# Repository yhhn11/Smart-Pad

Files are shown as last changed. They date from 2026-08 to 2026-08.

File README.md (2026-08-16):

# Smart-Pad

**Smart-Pad** is an open-source, 3D-printed, automated optical reader for colorimetric assays.

A stepper motor rotates a circular sample plate underneath an **AS7341 11-channel spectral
sensor**. For every position the plate stops, the sensor's white LED illuminates the sample and
the light returned by it is recorded in **8 wavelength bands (415, 445, 480, 515, 555, 590, 630
and 680 nm)**. The result of each sample is either the raw sensor counts or an absorbance value
calculated against a blank, and it is sent to your phone/computer over Wi-Fi.

Everything is controlled by an **ESP32**, and the whole build is designed to be reproducible by
someone with no electronics background: print the parts, make about a dozen soldered
connections, install two free programs and click one button to load the firmware.

> **No programming knowledge is required to build and use the device.** Section 5 explains how
> the code works only for those who want to modify or calibrate it.

---

## Table of contents

1. [Choosing a firmware version: MQTT or Web server](#1-choosing-a-firmware-version-mqtt-or-web-server)
2. [Bill of materials](#2-bill-of-materials)
3. [Step 1 — Print the parts](#3-step-1--print-the-parts)
4. [Step 2 — Wire the electronics](#4-step-2--wire-the-electronics)
5. [Step 3 — Flash the firmware onto the ESP32](#5-step-3--flash-the-firmware-onto-the-esp32)
6. [Step 4 — Run a measurement](#6-step-4--run-a-measurement)
7. [Step 5 — How the code works](#7-step-5--how-the-code-works)
8. [Troubleshooting](#8-troubleshooting)
9. [License](#9-license)

---

## 1. Choosing a firmware version: MQTT or Web server

This repository contains **two independent firmwares** for exactly the same hardware. You build
the device once, then choose which of the two programs to load onto the ESP32. You can switch
between them at any time by simply flashing the other one — nothing in the hardware changes.

**The measurement itself is identical in both.** Same pinout, same homing routine, same plate
map, same number of readings per sample, same filtering, same absorbance maths, same validation
limits. The only thing that differs is **how the device talks to you**:

| | **`WEBSERVER VERSION`** | **`MQTT VERSION`** |
|---|---|---|
| **How you talk to it** | The ESP32 **creates its own Wi-Fi network**. You connect your phone or laptop to it and open a web page hosted by the device. | The ESP32 **joins your existing Wi-Fi** and exchanges short text messages with an MQTT broker (a small message server). |
| **Infrastructure needed** | None. | A Wi-Fi network + an MQTT broker running somewhere (e.g. Mosquitto on a PC or Raspberry Pi). |
| **User interface** | A ready-made control page with sliders and a results panel (built into the firmware, no app to install). | None included — you use any MQTT client (MQTT Explorer, Node-RED, Home Assistant, a Python script…). |
| **Internet / lab network** | Works anywhere, even with no network at all (a field or a fume hood with no coverage). | Requires the device and your computer to be on the same network as the broker. |
| **Data logging** | Manual — you read the numbers off the web page, which shows one position at a time. | Automatic — every result is published as it is measured, so anything subscribed to the topic keeps the full run. |
| **Multiple devices** | One device = one Wi-Fi network to connect to; you must switch networks to change device. | Many devices can publish to the same broker at once and be monitored from one screen. |
| **Diagnostics** | Serial monitor over USB (115200 baud). | Published to the `Debug` and `Notifications` topics — readable over the air. |
| **Remote firmware update** | No. | Yes (ElegantOTA — update over Wi-Fi at `http://<device-ip>/update`). |
| **Difficulty** | ⭐ Easiest — start here | ⭐⭐ Requires setting up a broker |

**Which one should I use?**

- **You just want to measure samples** → use the **Web server version**. It is self-contained:
  turn the device on, connect your phone to it, press a button, read the numbers.
- **You want the data to be logged automatically**, to run several Smart-Pads in a lab, or to
  integrate the readings into an existing system → use the **MQTT version**.

Because the measurement code is shared, a plate calibration (§7.4) done on one version is valid
on the other, and readings taken with either firmware are directly comparable.

---

## 2. Bill of materials

### Electronics

| Qty | Component | Notes |
|:---:|---|---|
| 1 | **ESP32 DevKit V1** (30 or 38 pin) | The "brain". Any common ESP32 DevKit board works. |
| 1 | **AS7341** spectral sensor breakout | The detector. Must have the on-board white LED (Adafruit and most clones do). |
| 1 | **28BYJ-48 stepper motor (5 V)** + **ULN2003 driver board** | Usually sold together as a kit. Rotates the sample plate. |
| 1 | **KY-010 photo-interrupter module** | Optical endstop — tells the device where "position zero" is. |
| 1 | **PD/QC/AFC Fast-Charge Decoy Trigger module (Type-C)** | Turns any USB-C phone charger into a 5 V power supply for the device. |
| 1 | USB-C charger, **5 V, 2 A or more** | Powers the whole device through the decoy module. |
| 1 | USB **data** cable for the ESP32 (micro-USB or USB-C) | Needed only to load the firmware. Many cheap cables are charge-only and will *not* work. |
| — | Thin wires (AWG 24–26) and solder | About a dozen connections. Dupont jumper wires also work but are less reliable. |

### Printed parts

9 STL files, listed in [Step 1](#3-step-1--print-the-parts). One standard 1 kg spool of filament
is more than enough for the whole set.

### Tools

Soldering iron, side cutters, a small screwdriver, and a 3D printer (or a printing service).

---

## 3. Step 1 — Print the parts

All models are in the `3D PIECES TO PRINT/` folder, already in **STL** format — drop them
straight into your slicer (Cura, PrusaSlicer, Bambu Studio, Orca…).

### 3.1 Parts list

| File | Qty | Footprint (X × Y × Z, mm) | What it is |
|---|:---:|---|---|
| `BODY/SampleBase.stl` | 1 | 184 × 176 × 46 | Main chassis. The sample plate sits on it. **Largest part.** |
| `BODY/EletronicsBase.stl` | 1 | 184 × 166 × 43 | Compartment underneath that holds the ESP32, the driver board and the power module. |
| `BODY/SamplePlate.stl` | 1 | 140 × 140 × 11.4 | The rotating carousel that carries your samples. |
| `BODY/MotorConnector.stl` | 1 | 60 × 60 × 11.6 | Couples the 28BYJ-48 shaft to the sample plate. |
| `BODY/Cover.stl` | 1 | 166 × 166 × 30 | Lid that closes the device and keeps ambient light out. |
| `BODY/Sensor_Hinge v11.stl` | 1 | 28.7 × 24 × 10 | Hinge that holds the sensor head above the plate. |
| `SENSOR CASE/base.stl` | 1 | 44 × 26.5 × 16 | Bottom half of the AS7341 enclosure. |
| `SENSOR CASE/lid.stl` | 1 | 44 × 22.3 × 2.9 | Top half of the AS7341 enclosure. |
| `SENSOR CASE/Corpo3.stl` | 1 | 18 × 12 × 10.5 | Small rectangular block that fits inside the sensor case (light shield / spacer). |

> **Printer size check:** the largest parts need a bed of at least **190 × 180 mm**. A standard
> Ender-3 / Prusa i3 class printer (220 × 220 mm) is fine. A Prusa Mini (180 × 180 mm) is **not**
> big enough for `SampleBase.stl` or `EletronicsBase.stl`.

### 3.2 Recommended print settings

| Setting | Value | Why |
|---|---|---|
| **Material** | PLA or PETG | PETG if the device will sit somewhere warm. |
| **Colour** | **Black or another opaque dark colour** | This is an *optical* instrument. Light-coloured or translucent filament lets ambient light leak into the measurement chamber and will degrade your results. This matters most for `SampleBase`, `SamplePlate`, `Cover` and the sensor case. |
| **Layer height** | 0.2 mm | Good balance of speed and detail. |
| **Walls / perimeters** | 3 | Rigidity — the plate must not flex. |
| **Infill** | 20–25 % | |
| **Supports** | On, "touching build plate" | Check the slicer preview for each part: the hinge and the sensor case have small overhangs. |
| **Brim** | Recommended on the tall parts | Prevents the big flat parts from lifting at the corners. |

**Orientation:** print every part with its largest flat face on the bed. `SamplePlate` and
`Cover` should be printed flat (they are essentially discs). Print the sensor case `base` with
its open side up.

**Dimensional accuracy matters** for `MotorConnector` (it must grip the motor shaft) and for
`SamplePlate` (its holes must line up with the sensor). If your printer over-extrudes, the shaft
hole may come out too tight — a light pass with a hobby knife or a drill bit is normally enough.

Expect roughly a full day of printing (~20–30 h) for the complete set on a typical FDM printer;
your slicer will give the exact figure.

---

## 4. Step 2 — Wire the electronics

The system runs on a single 5 V rail. The USB-C decoy module negotiates 5 V from a phone
charger, feeds the ESP32 and the motor driver, and the ESP32's own 3.3 V regulator then powers
the two sensors.

### 4.1 Power distribution (the 5 V rail)

```
        USB-C wall charger  —  5 V, 2 A or more
                        │
                        │  USB-C cable
                        ▼
          ┌────────────────────────────┐
          │   PD/QC/AFC decoy module   │
          │      set to 5 V output     │
          └────┬──────────────────┬────┘
            5V │                  │ GND
               │                  │
               ├──► ESP32   VIN   ├──► ESP32   GND
               │                  │
               └──► ULN2003  +    └──► ULN2003  −

   The ESP32's own 3.3 V regulator then powers the two sensors:

          ESP32 3V3 ──┬──► AS7341 VIN            ESP32 GND ──┬──► AS7341 GND
                      └──► KY-010 + (middle)                 └──► KY-010 −
```

### 4.2 Signal connections

```
                            ESP32 DevKit V1
                        ┌───────────────────────┐
      ULN2003  IN1 ◄────┤ GPIO27         GPIO21 ├────► AS7341  SDA
      ULN2003  IN2 ◄────┤ GPIO25         GPIO22 ├────► AS7341  SCL
      ULN2003  IN3 ◄────┤ GPIO33                │
      ULN2003  IN4 ◄────┤ GPIO32            3V3 ├──┬─► AS7341  VIN
                        │                       │  └─► KY-010  + (middle pin)
      KY-010     S ─────┤ GPIO18                │
                        │                   GND ├──┬─► AS7341  GND
      5 V from decoy ──►┤ VIN                   │  └─► KY-010  −
      GND from decoy ──►┤ GND                   │
                        └───────────────────────┘

      ULN2003 white 5-pin connector ──────► 28BYJ-48 stepper motor
```

The ESP32 DevKit has several `GND` pins and they are all connected internally — use whichever is
most convenient. The `3V3` pin is an **output** from the on-board regulator; never feed 5 V into
it.

### 4.3 Connection tables

**Power — USB-C decoy module → everything else**

| Decoy module | Goes to |
|---|---|
| `+` / `5V` output | ESP32 **`VIN`** pin (labelled `5V` on some boards) |
| `+` / `5V` output | ULN2003 **`+`** terminal |
| `−` / `GND` output | ESP32 **`GND`** pin |
| `−` / `GND` output | ULN2003 **`−`** terminal |

Most decoy modules select their output voltage with a small button or a solder jumper — set it
to **5 V** and confirm with a multimeter *before* connecting anything else. Feeding 9 V or
12 V into `VIN` will destroy the ESP32.

**Stepper motor — ESP32 → ULN2003 → 28BYJ-48**

| ESP32 pin | ULN2003 pin |
|---|---|
| `GPIO27` | `IN1` |
| `GPIO25` | `IN2` |
| `GPIO33` | `IN3` |
| `GPIO32` | `IN4` |

The 28BYJ-48 plugs into the white 5-pin connector on the driver board — it only fits one way.

**Spectral sensor — ESP32 → AS7341 (I²C bus)**

| ESP32 pin | AS7341 pin |
|---|---|
| `3V3` | `VIN` (or `VCC`) |
| `GND` | `GND` |
| `GPIO21` | `SDA` |
| `GPIO22` | `SCL` |

> The AS7341 is powered from the ESP32's **3.3 V** output, never from 5 V, and its `INT`,
> `GPIO` and `LED` pads are left unconnected — the firmware drives the illumination LED through
> the I²C bus.

**Endstop — ESP32 → KY-010 photo-interrupter**

| ESP32 pin | KY-010 pin |
|---|---|
| `GPIO18` | `S` (signal) |
| `3V3` | middle pin (`+`) |
| `GND` | `−` |

The KY-010 straddles a tab on the rotating plate. Each revolution the tab passes through the
slot, the light beam is interrupted and the output changes state — that is how the device finds
its "home" position before every run.

### 4.4 Safety and good practice

- **Common ground is mandatory.** Every `GND` in the tables above must end up on the same
  electrical node. Most confusing failures in DIY builds come from a missing ground link.
- **Never connect 5 V to the ESP32's `3V3` pin.**
- **Unplug the USB-C charger while flashing the firmware over USB**, and unplug the USB cable
  when running from the charger. Powering the board from two sources at once is a common way
  to damage a devkit.
- The illumination LED can be configured up to 258 mA. Everything on the sensor side runs off
  the ESP32's small on-board 3.3 V regulator, so **start at 100 mA or less**. If the board keeps
  rebooting when the LED turns on, your supply or that regulator is being overloaded — lower the
  current.
- Solder joints beat Dupont jumpers here: the plate vibrates while the motor steps, and a jumper
  that works loose mid-run silently ruins a measurement.

---

## 5. Step 3 — Flash the firmware onto the ESP32

"Flashing" just means copying the program into the ESP32's memory. It is done once, from a
computer, with two free programs. Total time: about 20 minutes, most of it downloads.

### 5.1 Install Visual Studio Code

Download it from **<https://code.visualstudio.com/>** and install it with the default options
(Windows, macOS and Linux are all supported).

### 5.2 Install the PlatformIO extension

1. Open VS Code.
2. Click the **Extensions** icon in the left bar (four small squares), or press
   `Ctrl+Shift+X` (`Cmd+Shift+X` on macOS).
3. Type **`PlatformIO IDE`** in the search box and click **Install** on the first result.
4. **Wait.** The first installation downloads a few hundred megabytes and can take 5–10 minutes.
   A "PlatformIO: installing core" message appears at the bottom right; when it finishes, VS Code
   asks to reload — accept.
5. When it is ready, a small **alien head icon** appears in the left bar and a blue toolbar
   appears at the bottom of the window.

### 5.3 Download this repository

Either:

- On the GitHub page, click the green **`Code`** button → **`Download ZIP`**, then extract the
  ZIP somewhere permanent (e.g. `Documents`). **Do not work inside the ZIP file itself.**
- Or, if you have Git installed:

```bash
git clone https://github.com/yhhn11/Smart-Pad.git
```

### 5.4 Open the correct folder

This is the step people get wrong most often.

In VS Code: **File → Open Folder…**, and select **either**

```
Smart-Pad/WEBSERVER VERSION
```

**or**

```
Smart-Pad/MQTT VERSION
```

Open the **version folder itself, not the `Smart-Pad` root folder.** PlatformIO expects the
`platformio.ini` file to be at the top of whatever folder you opened; if you open the root it
will not recognise the project.

The first time you open a version, PlatformIO downloads the ESP32 toolchain and the required
libraries (Adafruit AS7341, AccelStepper, and so on). This takes a few minutes and needs an
internet connection. Let the bottom status bar go quiet before continuing.

### 5.5 Enter your settings in `config.h`

**This repository contains no passwords.** Every credential lives in a single file that you fill
in yourself. In the VS Code file explorer, open **`include/config.h`** and replace each
`CHANGE_ME…` placeholder.

**Web server version** — `WEBSERVER VERSION/include/config.h`:

```cpp
#define AP_SSID      "CHANGE_ME_NETWORK_NAME"   // name of the Wi-Fi network the device creates
#define AP_PASSWORD  "CHANGE_ME_PASSWORD"       // at least 8 characters, or the AP won't start
```

**MQTT version** — `MQTT VERSION/include/config.h`:

```cpp
#define WIFI_SSID       "CHANGE_ME_WIFI_NAME"       // your existing 2.4 GHz Wi-Fi
#define WIFI_PASSWORD   "CHANGE_ME_WIFI_PASSWORD"
#define MQTT_SERVER     "CHANGE_ME_BROKER_IP"       // e.g. "192.168.0.100"
#define MQTT_PORT       1883
#define MQTT_USER       "CHANGE_ME_MQTT_USER"
#define MQTT_PASSWORD   "CHANGE_ME_MQTT_PASSWORD"
#define MQTT_CLIENT_ID  "Smart_Pad01"               // must be unique if you run several devices
#define OTA_USER        "CHANGE_ME_OTA_USER"        // login for the wireless-update web page
#define OTA_PASSWORD    "CHANGE_ME_OTA_PASSWORD"
```

The MQTT topic names are in the same file if you want to change them.

> 🔒 **Once filled in, `config.h` contains your passwords.** Keep it to yourself; if you publish
> your own fork of this repository, blank the file out first.

> ℹ️ The ESP32 only supports **2.4 GHz** Wi-Fi. If your router publishes 2.4 and 5 GHz under the
> same name, the device may still fail to connect — give the 2.4 GHz band its own SSID.

### 5.6 Install the USB driver (Windows/macOS)

The ESP32 talks to your computer through a USB-to-serial chip. If no new COM port appears when
you plug the board in, install the driver for your board's chip — printed on the small square
chip near the USB connector:

- **CP2102 / CP2104** → Silicon Labs CP210x driver:
  <https://www.silabs.com/developer-tools/usb-to-uart-bridge-vcp-drivers>
- **CH340 / CH9102** → WCH driver: <https://www.wch-ic.com/downloads/CH341SER_EXE.html>

Most Linux distributions need no driver at all, but your user may need to be in the `dialout`
group.

### 5.7 Build and upload

1. **Disconnect the 5 V supply** from the decoy module. The board is powered by USB during this
   step.
2. Connect the ESP32 to the computer with a **data-capable** USB cable.
3. In the blue bar at the bottom of VS Code, click the **✓ (checkmark)** — *Build*. The terminal
   should end with a green **`[SUCCESS]`** and a memory report. This only compiles; nothing has
   been sent to the board yet.
4. Click the **→ (right arrow)** — *Upload*. PlatformIO finds the serial port automatically,
   compiles again and writes the firmware. Success looks like:

   ```
   Writing at 0x000... (100 %)
   Hash of data verified.
   Leaving... Hard resetting via RTS pin...
   ========================= [SUCCESS] Took 33.62 seconds =========================
   ```

5. If it fails with **`Failed to connect to ESP32: Timed out waiting for packet header`**: click
   Upload again and hold the **`BOOT`** button on the board down while the terminal shows
   `Connecting....`, releasing it once the upload starts. Some boards need this every time.

The board reboots and starts running the program immediately.

### 5.8 Check that it is alive

**Web server version** — click the **plug icon** in the bottom bar to open the Serial Monitor
(115200 baud, already configured). Press the board's `EN`/`RST` button; you should see:

```
IP Address: 192.168.4.1
Smart Pad initialized and ready
```

If `AS7341 sensor initialization failed, check the wiring` repeats once a second instead of the
"ready" line, the access point is up but the sensor is not answering — see
[Troubleshooting](#8-troubleshooting).

**MQTT version** — this firmware prints **nothing** to the serial port; all of its diagnostics
are published to MQTT. Subscribe to `Smart/Pad01/Notifications` and `Smart/Pad01/Debug` with any
MQTT client and reset the board. You should receive the device's IP address followed by
`Smart Pad 01 initialized and ready`.

### 5.9 Later updates (MQTT version only)

Once the MQTT firmware is running you never need the USB cable again. Open
`http://<device-ip>/update` in a browser, log in with your `OTA_USER` / `OTA_PASSWORD`, and
upload the new `firmware.bin` (PlatformIO leaves it in
`.pio/build/esp32doit-devkit-v1/firmware.bin`).

---

## 6. Step 4 — Run a measurement

### 6.1 Before every run

1. **The device always reads one extra position first — index 0**, before the samples you asked
   for. In **absorbance** mode that position is the **blank/reference** and is reported as eight
   zeros; in **raw** mode it is simply the first reading. So a run of *N* samples occupies
   *N + 1* positions on the plate. Load the plate accordingly (see §7.5).
2. Fill the positions in order, starting from the one immediately after the home tab.
3. Close the cover. Ambient light is the main source of error in this instrument.
4. Power the device from the USB-C charger.

### 6.2 Web server version

1. On your phone or laptop, connect to the Wi-Fi network named by `AP_SSID`, using `AP_PASSWORD`.
2. Open a browser at **<http://192.168.4.1>**.
3. Set the four parameters:

| Parameter | Range | Meaning |
|---|---|---|
| **Gain** | 1× … 512× | Sensor amplification. Increase it for dark/absorbing samples, decrease it if readings saturate at 65535. |
| **LED current** | 4 – 258 mA | Illumination brightness. Start around 100 mA. |
| **Number of samples** | 1 – 22 | How many positions to read after the blank. |
| **Sample type** | Raw / Absorbance | Raw counts, or absorbance against the first reading. |

4. Press **Send Setup**. The plate homes itself, moves to the first cell and starts reading.
   Results appear in the *Results* panel, one position at a time, refreshed once per second.
   Each position takes roughly 8–10 s (20 readings plus the move), so a 10-sample run takes a
   couple of minutes. The Start button re-enables itself when the run is over.

Every value is range-checked by the firmware, exactly as in the MQTT version. If you send
something out of range the device refuses to start and the page shows the reason.

> ℹ️ The web page only ever shows the **position being measured right now** — it is a live
> display, not a log. If you need the complete run recorded automatically, use the MQTT version.

### 6.3 MQTT version

Send a **setup message** to the topic `Smart/Pad01/Setup`, as four comma-separated numbers:

```
sampleType,numberOfSamples,gain,ledCurrent
```

| Field | Range | Meaning |
|---|---|---|
| `sampleType` | `0` or `1` | 0 = Raw, 1 = Absorbance |
| `numberOfSamples` | 1 – 22 | Positions to read after the blank |
| `gain` | 1, 2, 4, 8, 16, 32, 64, 128, 256, 512 | Sensor gain |
| `ledCurrent` | 4 – 258 | LED current in mA |

Example — 5 samples in absorbance mode, gain 64×, LED at 100 mA:

```
1,5,64,100
```

Every field is validated; an invalid value is rejected with a message on
`Smart/Pad01/Debug` and the run does not start.

**Topics published by the device**

| Topic | Content |
|---|---|
| `Smart/Pad01` | One line per position: `index,ch415,ch445,ch480,ch515,ch555,ch590,ch630,ch680` (3 decimals) |
| `Smart/Pad01/Notifications` | `Setup OK, starting measurement`, `Measurements finished`, boot messages, errors |
| `Smart/Pad01/Debug` | Homing confirmation, device IP, validation errors |

A result line looks like this:

```
3,1204.550,1876.300,2210.100,3011.750,2890.200,2455.000,1988.400,1502.650
```

Any MQTT client can capture this. Piping the `Smart/Pad01` topic into Node-RED, Home Assistant
or a five-line Python script with `paho-mqtt` gives you an automatic CSV log of every run.

---

## 7. Step 5 — How the code works

This section is for anyone who wants to calibrate, modify or simply understand the firmware.
**You do not need to read it to use the device.**

### 7.1 File map

```
MQTT VERSION/  |  WEBSERVER VERSION/
├── platformio.ini      Project settings: board, framework and the list of libraries
│                       PlatformIO downloads automatically
├── include/
│   ├── config.h        ← YOUR settings (Wi-Fi, MQTT, passwords). The only file you edit.
│   └── webpage.h       (web server version only) The entire control page — HTML, CSS and
│                       JavaScript — stored as one long string in the ESP32's flash memory
└── src/
    └── main.cpp        The whole firmware: ~330 lines
```

Everything below `setupWebRoutes()` / `mqtt_callback()` — the motion, the sensor handling and the
maths — is **the same code in both versions**. Only the communication layer differs.

### 7.2 Boot sequence (`setup()`)

Both follow the same principle: **bring the communication channel up first, then the sensor**, so
that a hardware fault can still be reported to you instead of failing silently.

| Web server version | MQTT version |
|---|---|
| 1. Start the serial port (115200 baud) for debug messages | 1. Connect to your Wi-Fi; reboot automatically after 20 failed attempts (10 s) |
| 2. Create the Wi-Fi access point | 2. Start the OTA update web server on port 80 |
| 3. Register the web routes `/`, `/setup`, `/data` and start the server | 3. Connect to the MQTT broker, retrying every 5 s, then subscribe to the setup topic |
| 4. Initialise the AS7341, printing an error on every failed attempt until it answers | 4. Initialise the AS7341, publishing an error message on every failed attempt until it answers |
| 5. Configure integration time and turn the LED off | 5. Configure integration time and turn the LED off |
| 6. Configure the motor pins and the endstop, then de-energise the motor coils | 6. Configure the motor pins and the endstop, then de-energise the motor coils |
| 7. Print `Smart Pad initialized and ready` | 7. Publish its IP address and `Smart Pad 01 initialized and ready` |

Because the AS7341 is initialised in a retry loop, a device whose sensor is unplugged still
serves its web page (or stays connected to the broker) and tells you what is wrong — it simply
never starts measuring.

Sensor configuration is identical in both:

```cpp
as7341.setATIME(100);
as7341.setASTEP(999);
```

Integration time = `(ATIME + 1) × (ASTEP + 1) × 2.78 µs` ≈ **281 ms per reading**. Longer
integration means more light collected and less noise, at the cost of speed. The ADC saturates
at **65535 counts** — a channel sitting at that value is over-range, and you must reduce the gain
or the LED current.

### 7.3 The main loop is a state machine

`loop()` does nothing at all until a valid setup arrives (from the web page or from MQTT). Then
it works through the plate one position per iteration:

```mermaid
flowchart TD
    A["Idle — waiting for a setup"] -->|Setup received and validated| B["Turn LED on,<br/>energise motor coils"]
    B --> C{"Already homed?"}
    C -->|No| D["resetPosition: rotate until the endstop<br/>triggers, then zero the step counter"]
    D --> E["Move to position 0 (the blank)"]
    C -->|Yes| F["Move to the next position"]
    E --> G["performSingleMeasurement"]
    F --> G
    G --> H["Publish / expose the 8 channel values"]
    H --> I{"Any position left?"}
    I -->|Yes| C
    I -->|No| J["LED off, coils off,<br/>report 'Measurements finished'"]
    J --> A
```

Two details worth knowing:

- **The coils are de-energised between runs** (`disableStepper()` writes all four pins LOW).
  A 28BYJ-48 that is left energised draws current continuously and gets hot for no benefit, since
  the plate does not need holding torque while idle.
- **Movement is blocking**: `while (stepper.distanceToGo() != 0) stepper.run();` — the firmware
  does nothing else while the plate turns. That is intentional; a measurement must never start
  before the plate has stopped.

### 7.4 Motion and homing

The motor is driven by the **AccelStepper** library in full-step mode:

```cpp
AccelStepper stepper(AccelStepper::FULL4WIRE, IN1, IN3, IN2, IN4);
```

The `IN1, IN3, IN2, IN4` order is not a typo — it matches the physical coil order of the
28BYJ-48. Getting it wrong makes the motor buzz and vibrate without turning.

A 28BYJ-48 makes about **2048 full steps per output revolution**, so the 85-step spacing used
between cells corresponds to roughly **15°**, i.e. about 24 positions around the plate.

**Homing (`resetPosition()`)** energises the coils, drives the plate backwards at a constant
speed (`setSpeed(-75)` + `runSpeed()`) until the KY-010 output goes `HIGH`, then declares that
point step zero. Every run starts this way, so the plate never accumulates error from one run to
the next. Both firmwares use the same routine and the same pin configuration:

```cpp
pinMode(PHOTOINTERRUPTER_PIN, INPUT);              // no internal pull-up
while (digitalRead(PHOTOINTERRUPTER_PIN) == LOW) { // keep turning while the beam is clear
    stepper.runSpeed();
}
```

If your KY-010 outputs the opposite polarity, invert that comparison — it is a one-word fix, and
it has to be made in whichever version you are using.

**Positioning (`moveToNextPosition()`)** converts a sample index into a number of steps. The map
is identical in both firmwares:

| Constant | Value | Role |
|---|---|---|
| `STEPS_TO_FIRST_CEL` | 5, applied **backwards** | Backs the plate off the home flag onto the blank position (index 0) |
| `STEPS_TO_FIRST_SAMPLE` | 95 | Blank position → first sample (index 1) |
| `STEPS_NEXT_CEL` | 85 | Spacing between two consecutive cells |
| `STEPS_CORRECTION` | 3 | Extra steps added on **every third position** |

`STEPS_CORRECTION` exists because a whole revolution is not an exact multiple of 85 steps: a
constant 85-step move slowly drifts off-centre, and the extra steps applied every third cell push
the plate back into alignment. **These constants are what you tune** if your printed plate ends up
slightly different from the original — misalignment shows up as readings that are fine at the
first positions and drift progressively at the last ones.

### 7.5 Taking one measurement (`performSingleMeasurement()`)

1. **Read the sensor `READINGS_PER_SAMPLE` times** — 20 repeats, 100 ms apart, in both versions.

2. **Keep 8 of the 12 values returned by the sensor.** `readAllChannels()` fills a 12-slot array
   in which positions 4, 5, 10 and 11 are the clear and near-infrared detectors. The firmware
   picks out the eight spectral channels:

   ```cpp
   const int channelMap[] = {0, 1, 2, 3, 6, 7, 8, 9}; // 415-680 nm
   ```

   | Index | 0 | 1 | 2 | 3 | 6 | 7 | 8 | 9 |
   |---|---|---|---|---|---|---|---|---|
   | **Channel** | F1 | F2 | F3 | F4 | F5 | F6 | F7 | F8 |
   | **Wavelength (nm)** | 415 | 445 | 480 | 515 | 555 | 590 | 630 | 680 |

3. **Average the repeats with `trimmedMeanFilter()`.** The 20 readings of each channel are
   sorted, the lowest 25 % and the highest 25 % are discarded, and only the middle 50 % is
   averaged (an interquartile mean). This rejects outliers caused by vibration, a flicker of
   ambient light or an I²C glitch, and is far more robust than a plain mean.

4. **Convert to the requested output.**

   - **Raw** (`sampleType = 0`) — the averaged counts are reported as they are. Use this for
     calibration, diagnostics, or when you want to do your own maths.
   - **Absorbance** (`sampleType = 1`) — the **first measurement of the run (index 0) is treated
     as the blank** and stored in `whiteValues[]`; it is reported as eight zeros. Every
     subsequent position is then reported as

     ```
     A = -log10(I_sample / I_blank)
     ```

     applied channel by channel — the standard definition of absorbance, referenced to the blank
     you loaded in position 0. A channel where either value is zero is reported as 0, to avoid a
     division by zero or the logarithm of zero.

     **Consequence:** a run of *N* samples in absorbance mode occupies *N + 1* positions on the
     plate — the blank plus the samples. Load the plate accordingly.

### 7.6 Communication layer

**Web server version** — three HTTP routes served by `ESPAsyncWebServer`:

| Route | Purpose |
|---|---|
| `GET /` | Returns the control page stored in `webpage.h` |
| `GET /setup?gain=…&current=…&samples=…&sampleType=…` | Validates the four parameters, configures the sensor and arms the state machine. Returns `409` if a measurement is already running, `400` if a parameter is missing or out of range (with the reason in `{"error":"…"}`), `500` if the sensor rejects the configuration. |
| `GET /data` | Returns the current state as JSON: `{"status":"measuring","sampleNumber":3,"isComplete":true,"channels":[…]}`, or `{"status":"idle","isComplete":true}` once the run is over |

The page polls `/data` once per second, refreshes the eight values on screen, and stops when the
device reports `idle`. The whole interface lives in the ESP32's flash memory — there is no app to
install and no internet access involved.

**MQTT version** — `mqtt_callback()` receives messages on the setup topic, parses the four
numbers with `sscanf`, then arms the state machine. Results are published from `loop()` as soon
as each position is measured, so a subscriber sees the run progress in real time instead of
waiting for the end.

**Both apply the same validation** before a run can start — `MIN_GAIN`/`MAX_GAIN`,
`MIN_LED_CURRENT`/`MAX_LED_CURRENT`, `MAX_SAMPLES` and the sample type — and both refuse the run
with an explanatory message if any value is out of range. The web version returns it as an HTTP
`400`, the MQTT version publishes it on the `Debug` topic.

### 7.7 Quick reference — constants you may want to change

All of these are at the top of `src/main.cpp` and hold **the same value in both firmwares** —
change one, change the other, and your two builds stay comparable.

| Constant | Default | Effect |
|---|---|---|
| `READINGS_PER_SAMPLE` | 20 | More readings = less noise, slower run |
| `MAX_SAMPLES` | 22 | Number of usable positions on the plate |
| `STEPS_NEXT_CEL` | 85 | Angular spacing between cells |
| `STEPS_CORRECTION` | 3 | Cumulative-error compensation, applied every third cell |
| `STEPS_TO_FIRST_CEL` | 5 | Backwards offset from the home flag to the blank position |
| `STEPS_TO_FIRST_SAMPLE` | 95 | Blank position → first sample |
| `setATIME` / `setASTEP` | 100 / 999 | Integration time (≈281 ms) |
| `setMaxSpeed` / `setAcceleration` | 200 / 40 | Plate speed. Too fast and the 28BYJ-48 skips steps and loses alignment. |
| `setSpeed(-75)` in `resetPosition()` | −75 | Homing speed |

If you change `MAX_SAMPLES`, update the `samples` slider's `max` attribute in
`WEBSERVER VERSION/include/webpage.h` to match, so the page cannot offer a value the firmware
will reject.

---

## 8. Troubleshooting

| Symptom | Likely cause and fix |
|---|---|
| **The plate spins forever and never stops homing** | The endstop logic is inverted for your KY-010. In `resetPosition()`, swap `LOW` for `HIGH` in the `while (digitalRead(PHOTOINTERRUPTER_PIN) == LOW)` condition. Also confirm the plate's tab actually passes through the sensor slot. |
| **`AS7341 sensor initialization failed…` repeats forever** | I²C wiring. Check `SDA`→`GPIO21`, `SCL`→`GPIO22`, that the sensor is on **3V3** and not 5 V, and that its ground is shared with the ESP32. A cold solder joint on `SDA`/`SCL` is the usual culprit. Both firmwares retry indefinitely, so the network stays up and the message keeps repeating until the sensor answers. |
| **The web page loads but nothing happens when I press Send Setup** | The sensor never initialised, so the device is still stuck in the retry loop and `loop()` is not running. Check the Serial Monitor — see the row above. |
| **Motor buzzes/vibrates but does not turn** | Coil order. Verify `GPIO27→IN1`, `GPIO25→IN2`, `GPIO33→IN3`, `GPIO32→IN4` and that the `AccelStepper` constructor still reads `IN1, IN3, IN2, IN4`. |
| **Motor does not move at all** | The ULN2003 `+`/`−` terminals are not connected to the 5 V supply. The driver board does not draw power from the ESP32. |
| **The board reboots when a measurement starts** | The LED current is too high for the supply. Lower it to 100 mA or less, and use a charger rated 2 A or more. |
| **All channels read 65535** | Saturation. Reduce the gain, reduce the LED current, or both. |
| **Readings drift for the last samples of a run** | Mechanical accumulation. Tune `STEPS_NEXT_CEL` / `STEPS_CORRECTION` (§7.4), and reduce `setMaxSpeed` if the motor is skipping steps. |
| **Upload fails: `Timed out waiting for packet header`** | Hold the `BOOT` button while PlatformIO prints `Connecting....`. Also check that the USB cable carries data and that the external 5 V supply is disconnected. |
| **No COM port appears** | Missing USB-serial driver (§5.6), or a charge-only USB cable. |
| **PlatformIO does not recognise the project** | You opened the `Smart-Pad` root folder instead of `MQTT VERSION` or `WEBSERVER VERSION` (§5.4). |
| **The ESP32 never joins the Wi-Fi (MQTT version)** | 2.4 GHz only, and the SSID/password in `config.h` are case-sensitive. The firmware reboots itself after ~10 s of failure, so a board that restarts in a loop is telling you the credentials are wrong. |
| **Erratic readings, poor reproducibility** | Ambient light. Close the cover, and reprint the optical parts in opaque dark filament if you used a light colour. |

---

## 9. License

MIT — see [LICENSE](LICENSE).

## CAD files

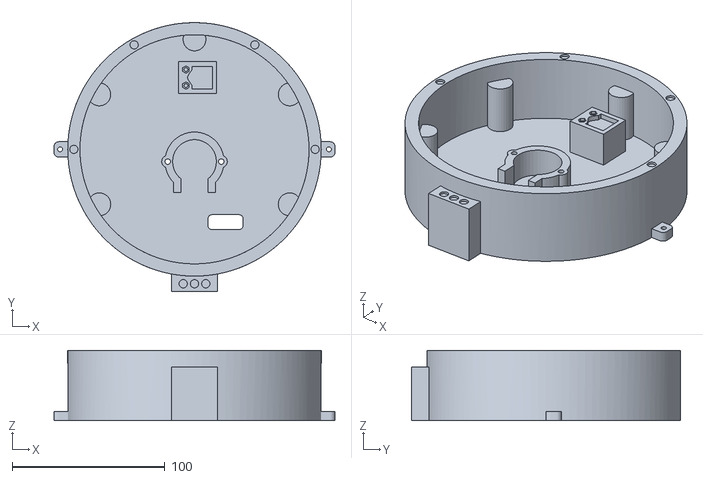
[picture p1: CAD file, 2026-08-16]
3D PIECES TO PRINT/BODY/SampleBase.stl
184.0 x 176.0 x 46.0

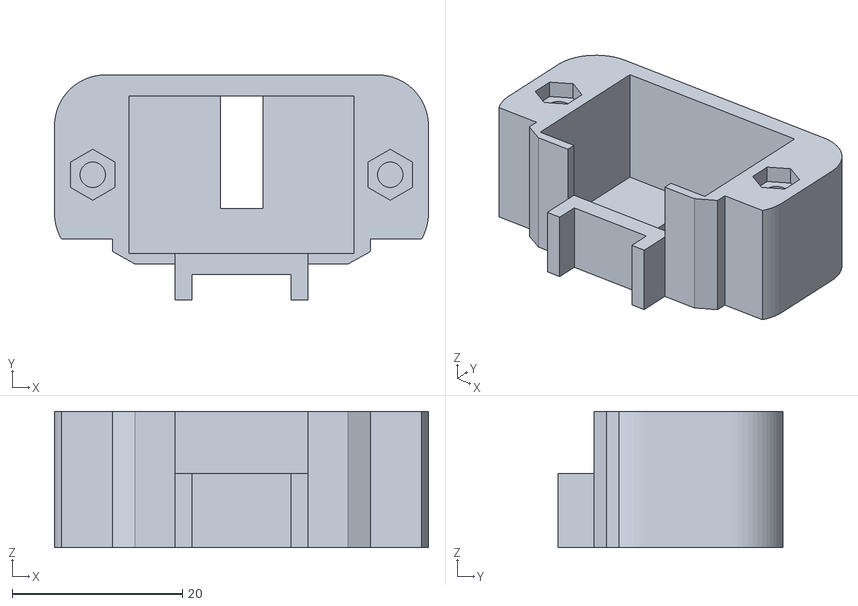
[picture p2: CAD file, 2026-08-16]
3D PIECES TO PRINT/SENSOR CASE/base.stl
44.0 x 26.5 x 16.0

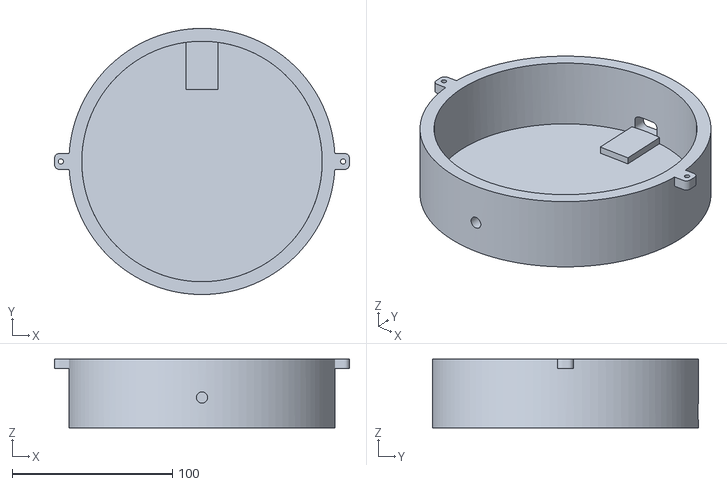
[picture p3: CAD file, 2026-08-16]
3D PIECES TO PRINT/BODY/EletronicsBase.stl
184.0 x 166.0 x 43.0

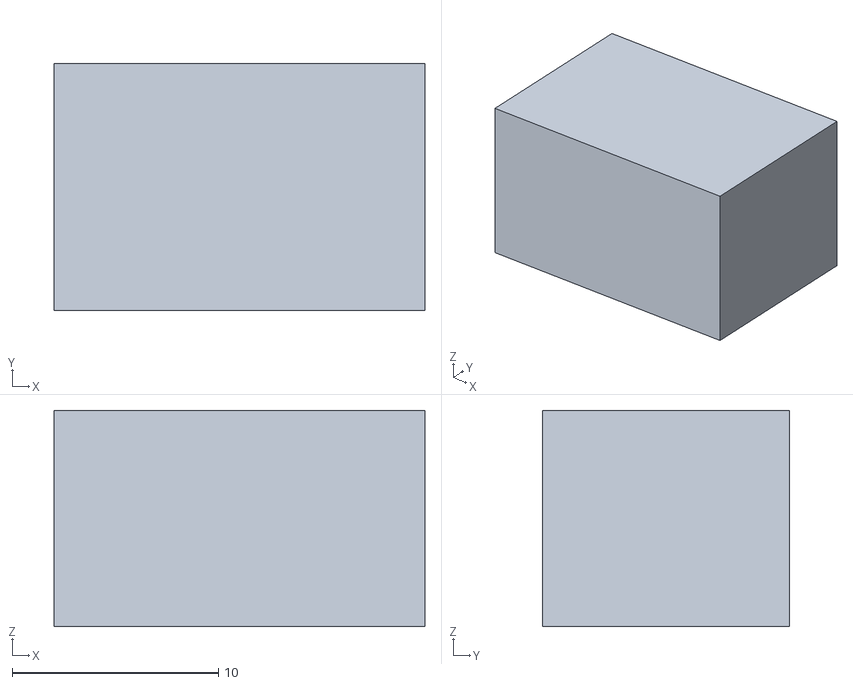
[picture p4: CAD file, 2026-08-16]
3D PIECES TO PRINT/SENSOR CASE/Corpo3.stl
18.0 x 12.0 x 10.5

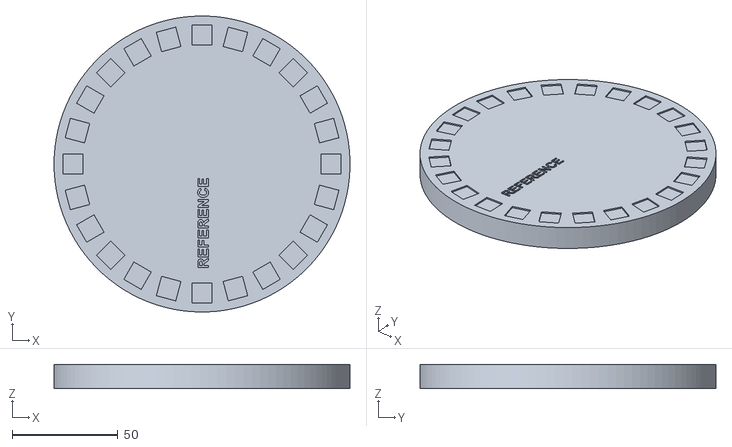
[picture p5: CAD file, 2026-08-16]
3D PIECES TO PRINT/BODY/SamplePlate.stl
140.0 x 140.0 x 11.4

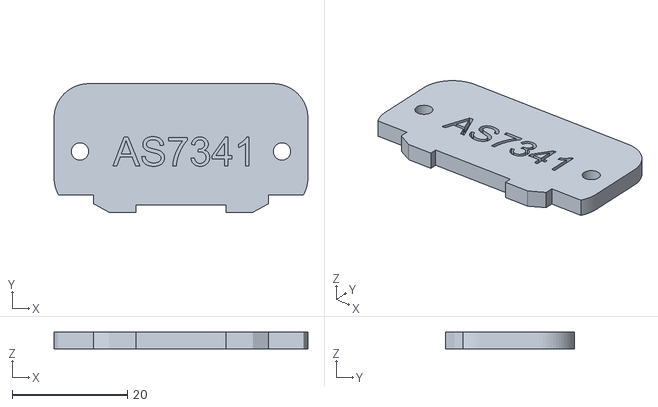
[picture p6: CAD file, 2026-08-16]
3D PIECES TO PRINT/SENSOR CASE/lid.stl
44.0 x 22.3 x 2.90

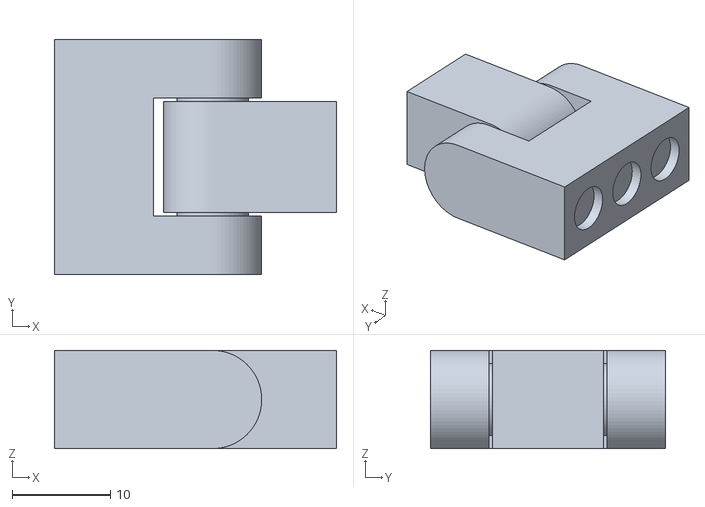
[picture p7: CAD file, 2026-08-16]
3D PIECES TO PRINT/BODY/Sensor_Hinge v11.stl
28.7 x 24.0 x 10.0

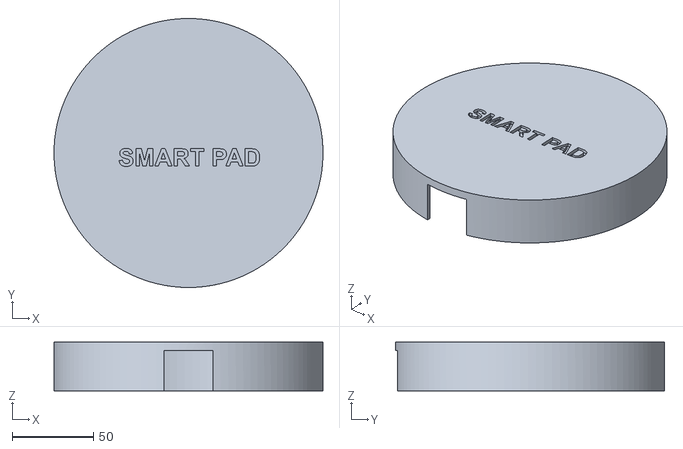
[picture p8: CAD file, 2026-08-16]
3D PIECES TO PRINT/BODY/Cover.stl
166.0 x 166.0 x 30.0

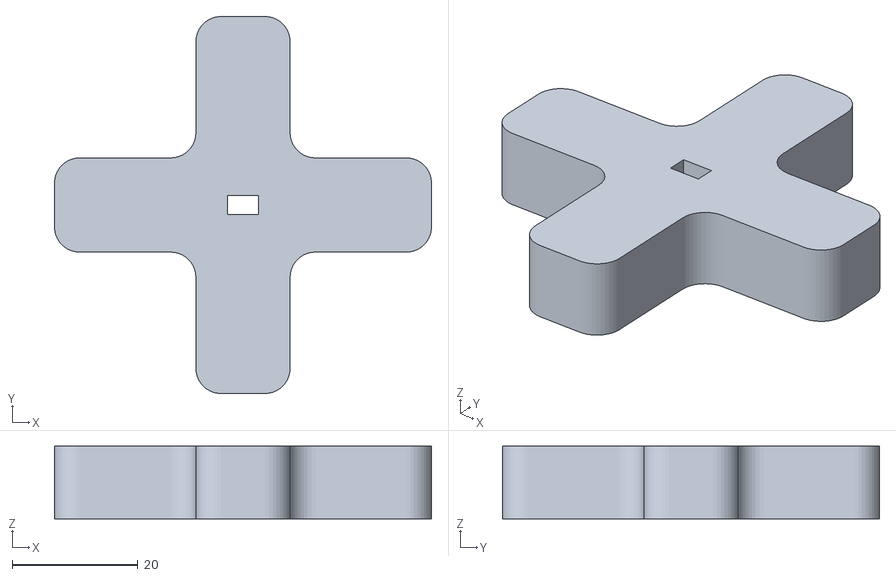
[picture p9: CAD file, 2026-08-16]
3D PIECES TO PRINT/BODY/MotorConnector.stl
60.0 x 60.0 x 11.6

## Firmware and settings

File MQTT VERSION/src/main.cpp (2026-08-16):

#include <Arduino.h>
#include <Adafruit_AS7341.h>
#include <AccelStepper.h>
#include <WiFi.h>
#include <PubSubClient.h>
#include <ElegantOTA.h>
#include "config.h"

// Pin definitions
#define IN1 27
#define IN2 25
#define IN3 33
#define IN4 32
#define PHOTOINTERRUPTER_PIN 18

#define STEPS_TO_FIRST_CEL 5
#define STEPS_NEXT_CEL 85
#define STEPS_CORRECTION 3
#define STEPS_TO_FIRST_SAMPLE 95
#define MIN_LED_CURRENT 4
#define MAX_LED_CURRENT 258
#define MIN_GAIN 1
#define MAX_GAIN 512
#define MAX_SAMPLES 22
#define NUM_CHANNELS 8
#define READINGS_PER_SAMPLE 20

char ssid[] = WIFI_SSID;
char password[] = WIFI_PASSWORD;

const char* mqtt_server = MQTT_SERVER;
const char* mqttUser = MQTT_USER;
const char* mqttPassword = MQTT_PASSWORD;
const char* mqtt_id = MQTT_CLIENT_ID;
const int   mqtt_port = MQTT_PORT;
const char  mqttTopic[] = MQTT_TOPIC_DATA;
const char  mqttTopicSetup[] = MQTT_TOPIC_SETUP;
const char  mqttTopicDebug[] = MQTT_TOPIC_DEBUG;
const char  mqttTopicNotifications[] = MQTT_TOPIC_NOTIFICATIONS;

WiFiClient wifiClient;
PubSubClient client(wifiClient);

// OTA system for web-based firmware updates
AsyncWebServer server(80);
const char* userOTA = OTA_USER;
const char* userPassWordOTA = OTA_PASSWORD;

// Global objects
AccelStepper stepper(AccelStepper::FULL4WIRE, IN1, IN3, IN2, IN4);
Adafruit_AS7341 as7341;

// Data structure holding the measurement configuration
struct MeasurementConfig {
    uint16_t gain = 1;
    uint16_t current = 100;
    uint16_t numSamples = 1;
    uint16_t sampleType = 0;
    bool isValid = false;
};

// Data structure holding the measurement results
struct MeasurementData {
    float channels[NUM_CHANNELS];
    int currentSample = 0;
    bool isComplete = false;
    bool inProgress = false;
    bool positionReset = false;
};

MeasurementConfig config;
MeasurementData measurementData;
float whiteValues[NUM_CHANNELS] = {0};

void enableStepper();
void disableStepper();
void resetPosition();
void moveToNextPosition(int currentSample);
bool configureSensor();
float trimmedMeanFilter(uint16_t samples[], int size);
void performSingleMeasurement();
void mqtt_callback(char* topic, byte* payload, unsigned int length);

void setup() {

    WiFi.mode(WIFI_STA);
    WiFi.begin(ssid, password);
    uint8_t attemptsWifi = 0;
    while (WiFi.status() != WL_CONNECTED){
        delay(500);
        attemptsWifi++;
        if (attemptsWifi > 20) {
            ESP.restart();
        }
    }

    server.on("/", HTTP_GET, [](AsyncWebServerRequest *request) {
    request->send(200, "text/plain", "Smart Pad 01");
    });
    ElegantOTA.setAutoReboot(true);
    ElegantOTA.setAuth(userOTA, userPassWordOTA);
    ElegantOTA.begin(&server);
    server.begin();

    client.setServer(mqtt_server, mqtt_port);
    client.setKeepAlive(3600);
    client.setCallback(mqtt_callback);
    while(!client.connected()){
        client.connect(mqtt_id, mqttUser, mqttPassword);
        delay(5000);
    }
    client.subscribe(mqttTopicSetup);

    while(!as7341.begin()) {
        client.publish(mqttTopicNotifications, "AS7341 sensor initialization failed, check the wiring");
    }
    as7341.setATIME(100);
    as7341.setASTEP(999);
    as7341.enableLED(false);

    pinMode(PHOTOINTERRUPTER_PIN, INPUT);
    pinMode(IN1, OUTPUT);
    pinMode(IN2, OUTPUT);
    pinMode(IN3, OUTPUT);
    pinMode(IN4, OUTPUT);

    stepper.setMaxSpeed(200);
    stepper.setAcceleration(40);
    stepper.setSpeed(20);

    disableStepper();

    String ipMessage;
    ipMessage =  "IP Smart_Pad_01 : " + WiFi.localIP().toString();
    client.publish(mqttTopicDebug, ipMessage.c_str());

    client.publish(mqttTopicNotifications, "Smart Pad 01 initialized and ready");
}

void loop() {
    client.loop();
    ElegantOTA.loop();
    if (config.isValid && measurementData.inProgress) {
        as7341.enableLED(true);
        enableStepper();
        if (!measurementData.positionReset) {
            resetPosition();
            moveToNextPosition(0);
            measurementData.positionReset = true;
            delay(500);
        } else if (measurementData.currentSample > 0 && measurementData.currentSample <= config.numSamples) {
            moveToNextPosition(measurementData.currentSample);
            delay(500);
        }
        if (measurementData.currentSample <= config.numSamples) {
            performSingleMeasurement();
            // Build the result string that gets published
            String result = String(measurementData.currentSample);
            for (int i = 0; i < NUM_CHANNELS; i++) {
                result += "," + String(measurementData.channels[i], 3);
            }
            client.publish(mqttTopic, result.c_str());
            measurementData.isComplete = true;
            measurementData.currentSample++;
        } else {
            measurementData.inProgress = false;
            config.isValid = false;
            measurementData.positionReset = false;
            as7341.enableLED(false);
            disableStepper();
            client.publish(mqttTopicNotifications, "Measurements finished");
        }
    }
}

void enableStepper() {
    digitalWrite(IN1, HIGH);
    digitalWrite(IN2, HIGH);
    digitalWrite(IN3, HIGH);
    digitalWrite(IN4, HIGH);
}

void disableStepper() {
    digitalWrite(IN1, LOW);
    digitalWrite(IN2, LOW);
    digitalWrite(IN3, LOW);
    digitalWrite(IN4, LOW);
}

void resetPosition() {
    enableStepper();
    stepper.setSpeed(-75);

    while (digitalRead(PHOTOINTERRUPTER_PIN) == LOW) {
        stepper.runSpeed();
    }

    stepper.stop();
    stepper.setCurrentPosition(0);
    measurementData.positionReset = true;
    client.publish(mqttTopicDebug, "Home position found, step counter reset.");
}

void moveToNextPosition(int currentSample) {
    int steps;

    if(currentSample == 0){
        steps = - STEPS_TO_FIRST_CEL;
    }
    else if(currentSample == 1){
        steps = STEPS_TO_FIRST_SAMPLE;
    }
    else if(currentSample % 3 == 0 && currentSample < MAX_SAMPLES + 1){
        steps = STEPS_NEXT_CEL + STEPS_CORRECTION;
    }
    else{
        steps = STEPS_NEXT_CEL;
    }

    stepper.move(steps);
    while (stepper.distanceToGo() != 0) {
        stepper.run();
    }
}

bool configureSensor() {
    as7341.setLEDCurrent(config.current);
    as7341_gain_t gainSetting;
    switch (config.gain) {
        case 1: gainSetting = AS7341_GAIN_1X; break;
        case 2: gainSetting = AS7341_GAIN_2X; break;
        case 4: gainSetting = AS7341_GAIN_4X; break;
        case 8: gainSetting = AS7341_GAIN_8X; break;
        case 16: gainSetting = AS7341_GAIN_16X; break;
        case 32: gainSetting = AS7341_GAIN_32X; break;
        case 64: gainSetting = AS7341_GAIN_64X; break;
        case 128: gainSetting = AS7341_GAIN_128X; break;
        case 256: gainSetting = AS7341_GAIN_256X; break;
        case 512: gainSetting = AS7341_GAIN_512X; break;
        default: return false;
    }
    as7341.setGain(gainSetting);
    return true;
}

float trimmedMeanFilter(uint16_t samples[], int size) {
    // Sort the sample array in ascending order
    for (int i = 0; i < size - 1; i++) {
        for (int j = i + 1; j < size; j++) {
            if (samples[j] < samples[i]) {
                uint16_t temp = samples[i];
                samples[i] = samples[j];
                samples[j] = temp;
            }
        }
    }
    // Index of the first and of the last quartile (25%)
    int firstQuartile = size / 4;
    int lastQuartile = firstQuartile * 3;

    // Sum the samples of the second and third quartiles (the middle 50%)
    float sum = 0.0;
    int count = 0;
    for (int i = firstQuartile; i < lastQuartile; i++) {
        sum += samples[i];
        count++;
    }
    // Return the mean of the second and third quartiles
    return sum / count;
}

void performSingleMeasurement() {

    uint16_t readings[READINGS_PER_SAMPLE][NUM_CHANNELS];

    for (int i = 0; i < READINGS_PER_SAMPLE; i++) {
        for (int j = 0; j < NUM_CHANNELS; j++) {
            readings[i][j] = 0;
        }
    }

    for (int i = 0; i < READINGS_PER_SAMPLE; i++) {
        uint16_t rawReadings[12];
        if (as7341.readAllChannels(rawReadings)) {
            const int channelMap[] = {0, 1, 2, 3, 6, 7, 8, 9}; // 415-680nm
            for (int j = 0; j < NUM_CHANNELS; j++) {
                readings[i][j] = rawReadings[channelMap[j]];
            }
        }
        delay(100);
    }

    float averages[NUM_CHANNELS];
    for (int i = 0; i < NUM_CHANNELS; i++) {
        averages[i] = 0.0;
    }

    for (int channel = 0; channel < NUM_CHANNELS; channel++) {
        uint16_t channelReadings[READINGS_PER_SAMPLE];
        for (int i = 0; i < READINGS_PER_SAMPLE; i++) {
            channelReadings[i] = 0;
        }
        for (int i = 0; i < READINGS_PER_SAMPLE; i++) {
            channelReadings[i] = readings[i][channel];
        }
        averages[channel] = trimmedMeanFilter(channelReadings, READINGS_PER_SAMPLE);
    }

    if (config.sampleType == 0) { // Raw
        for (int i = 0; i < NUM_CHANNELS; i++) {
            measurementData.channels[i] = averages[i];
        }
    } else { // Absorbance
        if (measurementData.currentSample == 0) {
            for (int i = 0; i < NUM_CHANNELS; i++) {
                whiteValues[i] = averages[i];
                measurementData.channels[i] = 0;
            }
        } else {
            for (int i = 0; i < NUM_CHANNELS; i++) {
                if (whiteValues[i] > 0 && averages[i] > 0) {
                    measurementData.channels[i] = -log10(averages[i] / whiteValues[i]);
                } else {
                    measurementData.channels[i] = 0;
                }
            }
        }
    }
}

void mqtt_callback(char* topic, byte* payload, unsigned int length) {

    char msg_mqtt[length + 1];
    memcpy(msg_mqtt, payload, length);
    msg_mqtt[length] = '\0';

    if(strcmp(topic, mqttTopicSetup) == 0){
        int type = 0, samples = 0, gain = 0, current = 0;
        int parsedFields = sscanf(msg_mqtt, "%d,%d,%d,%d", &type, &samples, &gain, &current);
        if(parsedFields == 4){
            if(samples <= 0 || samples > MAX_SAMPLES){
                client.publish(mqttTopicDebug, "Invalid number of samples");
                return;
            }
            if(type > 1 || type < 0){
                client.publish(mqttTopicDebug, "Invalid sample type");
                return;
            }
            if(current < MIN_LED_CURRENT || current > MAX_LED_CURRENT){
                client.publish(mqttTopicDebug, "Invalid LED current");
                return;
            }
            if(gain < MIN_GAIN || gain > MAX_GAIN){
                client.publish(mqttTopicDebug, "Invalid gain");
                return;
            }
            config.gain = gain;
            config.current = current;
            config.numSamples = samples;
            config.sampleType = type;
            if (!configureSensor()) {
                client.publish(mqttTopicDebug, "Sensor configuration failed");
                return;
            }
            measurementData.currentSample = 0;
            measurementData.isComplete = false;
            measurementData.inProgress = true;
            measurementData.positionReset = false;
            config.isValid = true;
            client.publish(mqttTopicNotifications, "Setup OK, starting measurement");
        } else {
            client.publish(mqttTopicNotifications, "Setup message not recognized!");
        }
    }
}

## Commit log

2026-08-16 Add initial implementation for SmartPad project with MQTT and web server
    - Created platformio.ini for project configuration with necessary libraries.
    - Implemented main functionality in src/main.cpp including WiFi connection, MQTT setup, and measurement logic.
    - Added webpage.h for serving a web interface to control the SmartPad.
    - Included measurement configuration and data structures for handling sensor readings.
    - Established routes for web server to handle setup and data requests.
    - Implemented stepper motor control for positioning during measurements.
    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
    [Connector_Motor_Sample.obj, Contact_switch.obj, Corpo3.stl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]
2026-08-16 Refactor web server version: Update webpage language to English, enhance error handling, and streamline polling logic.
    Update main application: Improve configuration handling, enhance measurement logic, and implement trimmed mean filter for readings.
    Add configuration header files: Introduce config.h for both MQTT and web server versions to centralize user settings for Wi-Fi and MQTT broker.
    [main.cpp]
